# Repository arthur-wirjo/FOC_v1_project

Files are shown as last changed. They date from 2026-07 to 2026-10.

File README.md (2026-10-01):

# DIY FOC Motor Controller V1: Custom Hardware & Firmware from Scratch 

FOC_v1 3_pic
FOC_v1 3_pic2
FOC_v1 3_setup2
FOC_v1 0-1 2

A custom-designed, 60V 50A Field Oriented Control (FOC) BLDC motor controller built from scratch. Designed for high-performance robotics, featuring a 4-layer power PCB, isolated USB telemetry, and CAN bus communication.

## Overview

I started this project to deeply understand the hardware architecture of modern, high-power motor drivers like the VESC and ODrive. Instead of just buying an off-the-shelf driver, I wanted to design one from the ground up to learn the intricacies of power electronics, mixed-signal PCB layout, gate driving, and hardware debugging.

The system is split into a 4-layer main power board (handling the MCU and 60V power stage) and a separate 2-layer magnetic encoder board mounted directly to the motor. This approach kept the overall footprint compact and reduced manufacturing costs.

As the project progressed, it evolved beyond "build a VESC clone" into writing a full custom bare-metal FOC firmware stack from scratch — more on why below. As of 28 September 2026, the board runs true closed-loop Field-Oriented Control, with working current control and smooth closed-loop velocity control of the motor.

## Key Features

* **Working Closed-Loop FOC:** Fully custom bare-metal firmware achieves smooth closed-loop current control and velocity control.
* **60V Power Stage:** 60V-rated MOSFETs capable of handling 10S Li-Po battery voltages and regenerative braking spikes.
* **Precision Current Sensing:** 1mΩ shunt resistors utilizing strict Kelvin connections and RC-filtered differential amplifiers.
* **Isolated Telemetry:** ADuM3160-based USB isolation to protect the host computer from catastrophic 60V transients during live tuning.
* **Robust Communication:** TJA1051T/3 CAN bus transceiver with 120Ω termination for robot networking.
* **Modular Encoder:** Separate 2-layer AS5048A magnetic encoder PCB using JST-GH SMD connectors.

## Hardware

### Computing & Control
* **Microcontroller:** STM32F405RGT6 (Chosen for its floating-point unit, advanced motor control timers, and native VESC compatibility)
* **Gate Driver:** TI DRV8301 (Features a built-in 5V buck converter and dual current shunt amplifiers. Chosen over the DRV8323 for VESC compatibility)

### Power Stage
* **MOSFETs:** Infineon IRFS7530 in D2PAK-7 (Rated for 60V, providing ample headroom for a 10S ~40V battery and regenerative braking)
* **Current Sense:** Yageo PU2512FK-070R001L (1mΩ, 2W metal alloy shunts)
* **Protection:** Littelfuse SMCJ43A TVS Diode (Clamps dangerous voltage spikes generated by motor back-EMF during hard braking)
* **Connectors:** Amass XT90-S (Anti-spark) for battery input

### Sensing & Telemetry
* **Encoder:** AMS AS5048A (14-bit absolute magnetic encoder reading a 6x2.5mm diametrically magnetized NdFeB magnet)
* **Temperature:** Murata 10kΩ 0603 NTC Thermistor (Placed directly adjacent to the MOSFETs to monitor power stage thermals)
* **Voltage Sensing:** 39kΩ / 2.2kΩ voltage divider to safely scale the 60V bus down to the STM32's 3.3V ADC range

## PCB Design & Layout

The board utilizes a 4-layer stackup to safely separate high-current paths from delicate digital signals:
* **Layer 1 (Top):** Components, massive copper polygons for Motor Phases and 42V supply.
* **Layer 2 (Inner 1):** Solid GND plane (Acts as an EMI shield for the signal layer).
* **Layer 3 (Inner 2):** Signal routing (SPI, CAN, Gate Drive traces).
* **Layer 4 (Bottom):** Additional GND and 42V copper pours, heavily via-stitched to the top layer to maximize current carrying capacity and thermal dissipation.

## Challenges and Lessons Learned

Building a high-power motor controller from scratch provided an intense, hands-on education in hardware and firmware debugging.

### Solder Wicking and Clearance Tolerances (V1.0)
After freshly soldering the V1.0 PCB, I felt an unusually strong resistance when I tried to rotate the motor by hand. I learned this is caused by back-EMF when phase wires are shorted together. Multimeter testing confirmed that V++, GND, and all three motor phases were dead-shorted.

Upon inspection, I realized the clearance between my GND copper pour and the soldering pads for V++ and the phase wires was very small (0.15mm). When hand-soldering the massive motor wires, the liquid solder easily wicked across that tiny gap into the GND pour.

For V1.1, I redesigned the board with strict Net Classes, increasing the clearance around high-power wire pads to 0.6mm to create a physical "moat", while keeping the MCU digital clearance at 0.15mm for dense routing.

### The "Bad Internet Symbol" Trap (V1.1)
After successfully assembling V1.1 with new stencils and corrected clearances, the board still exhibited a short between V++, GND, and the phase wires.

I started isolating the issue by desoldering components one by one. I checked a bare V1.0 board and found no shorts, meaning the layout itself wasn't fundamentally shorted. I desoldered the MCU and gate driver — the short was still there. Finally, I desoldered the high-side MOSFETs one by one. Removing the last high-side MOSFET finally severed the short between V++ and the motor phases.

I probed the desoldered MOSFET and found a short between Pin 7 and the Source pins (Pins 2-6). Initially, I thought the MOSFET had overheated and failed closed during hot-plate reflow. However, I looked into the Infineon datasheet and saw a catastrophic error in the third-party CAD symbol I had downloaded.

The symbol incorrectly labeled Pin 7 as "Drain". In reality, the D2PAK-7 package uses the large back EPAD as the Drain, and Pins 2 through 7 are *all* Source pins. Because I followed the flawed schematic, my PCB layout drew a massive copper pour that physically connected the Drain (EPAD) to the Source (Pin 7). The PCB itself was shorting the circuit by design, while the MOSFETs were actually unharmed.

**Lesson learned:** Never trust third-party CAD footprints without verifying against the manufacturer's datasheet.

### The USB D+/D- Swap (V1.2)
With the phase-short issue resolved, V1.2 soldered up cleanly with no shorts between V++, GND, or the phase wires. After hours of VESC firmware macro configuration, I successfully flashed VESC firmware onto the board. However, the board never enumerated over USB — nothing populated on the host PC.

I re-checked the firmware configuration and it looked correct, so I moved to the hardware. It turned out to be a wiring mistake on my end, though the confusing pin naming in the schematic symbol didn't help: instead of connecting DP1↔DP2 and DN1↔DN2 (the isolator-side and MCU-side USB differential pairs), I had wired DP1↔DN1 and DP2↔DN2 — crossing the differential pairs instead of linking them straight through. I corrected this for V1.3.

### The Mysterious Non-Enumerating USB (V1.3)
V1.3 fixed the DP/DN wiring mistake. USB still did not enumerate.

At this point I was confident the hardware was correct, so I wrote a minimal bare-metal STM32 firmware (via STM32CubeMX, STM32CubeIDE, and STM32CubeProgrammer) with nothing but a USB CDC "hello world" to test enumeration independently of VESC firmware. It worked immediately — the host PC detected the board and the virtual COM port came up cleanly. This confirmed the hardware (including the USB isolation and the DP/DN fix) was fine, and the problem was somewhere inside VESC firmware itself.

After a weekend of digging, my working theory is that VESC firmware assumes VBUS sensing on a specific pin by default, which on my board doesn't correspond to an actual VBUS-sensing net — that pin (PA9 / TIM1_CH2) is repurposed as a motor PWM output on my hardware. If VESC firmware is waiting on a VBUS-sense signal that physically doesn't exist on my board, USB enumeration would never complete, since the firmware assumes the connection is dead.

Rather than dig further into VESC's fairly large and unfamiliar codebase to patch around this, I decided to use this as an opportunity to learn embedded systems more deeply from first principles by writing my own bare-metal FOC firmware from scratch.

### The Deceiving Cogging Torque (Open-Loop Commutation)
After first achieving open-loop commutation, I later struggled to reproduce it and assumed something had regressed in the firmware. After investigation, I realized the real cause: during my initial successful test, the motor had warmed up from repeated open-loop parameter tuning, which reduced its cogging torque (magnetic detent force) enough for the open-loop drive to overcome it smoothly. On a cold motor, the same open-loop parameters weren't enough to break through cogging torque cleanly. This was a good reminder that motor behavior is temperature-dependent, and that "it worked once" isn't the same as "it's tuned correctly."

### Missing Bulk Decoupling Capacitor (Current Sensing Noise)
While debugging noisy phase current readings, a senior pointed out that the DRV8301's built-in 5V buck converter was missing a bulk decoupling capacitor on my board. Without it, switching-induced ripple on the 5V rail was likely feeding through to the gate driver's built-in current sense amplifiers, degrading signal quality. I added the missing capacitor directly onto the existing V1.3 board (Frankenstein-style, dead-bug soldered), which noticeably cleaned up the current readings enough for stable closed-loop control. This will be properly integrated into the layout for the next PCB revision.

## Custom Firmware Development

Since abandoning VESC firmware, I've been built a custom bare-metal firmware stack using STM32CubeMX, STM32CubeIDE, and FreeRTOS (for telemetry and state management), with the actual FOC control loop implemented as a hardware-timer/ADC-interrupt-driven routine.

### MCU Pinout

**PWM (TIM1, Center-Aligned, Complementary Outputs)**
| Pin | Function |
|---|---|
| PA8 | TIM1_CH1 |
| PA9 | TIM1_CH2 |
| PA10 | TIM1_CH3 |
| PB13 | TIM1_CH1N |
| PB14 | TIM1_CH2N |
| PB15 | TIM1_CH3N |

**ADC (Current & Voltage Sensing)**
| Pin | Function |
|---|---|
| PA0 | ADC1_IN0 — Phase A Current |
| PA1 | ADC2_IN1 — Phase C Current |
| PA2 | ADC3_IN2 — VBUS Voltage Sensing |
| PA3 | ADC3_IN3 — MOSFET Temperature |

**DRV8301 Gate Driver (SPI1)**
| Pin | Function |
|---|---|
| PC1 | EN_GATE |
| PC2 | DC_CAL |
| PC0 | nFAULT (EXTI0) |
| PB3 | SPI1_SCK |
| PB4 | SPI1_MISO |
| PB5 | SPI1_MOSI |
| PD2 | CS |

**Encoder (SPI3)**
| Pin | Function |
|---|---|
| PC10 | SPI3_SCK |
| PC11 | SPI3_MISO |
| PC12 | SPI3_MOSI |
| PA15 | CS |

**CAN**
| Pin | Function |
|---|---|
| PB8 | CAN1_RX |
| PB9 | CAN1_TX |

**USB**
| Pin | Function |
|---|---|
| PA11 | D- |
| PA12 | D+ |

> **Critical note:** VBUS sensing on PA9 is intentionally *not* used — PA9 is a motor PWM pin on this board (see the V1.3 debugging story above). USB is forced to enumerate without relying on VBUS sensing.

### STM32CubeMX Configuration Notes
* Deadtime configured on the PWM timer to prevent shoot-through.
* Center-aligned PWM mode for reduced current ripple.
* ADC sampling is hardware-synchronized to PWM switching using TIM1's "Update Event" as the ADC "Trigger Event Selection," so current is always sampled at a consistent point in the switching cycle.
* Third phase current is reconstructed using Kirchhoff's Current Law rather than measured directly (only two shunts are sensed).
* ADC current sensing uses **injected conversion mode** so it can be hardware-triggered directly by the timer.
* ADC interrupt enabled in NVIC settings for the current-sensing ADC.
* Encoder SPI configured with DMA in full-duplex master mode.
* USB configured using the USB CDC class for direct serial communication with the host PC.

### Firmware Development Progress
1. ✅ Pinout and hardware configuration in CubeMX
2. ✅ USB CDC enumeration working
3. ✅ DRV8301 register read helper function + gate driver wake-up sequence
4. ✅ SPI encoder DMA callback
5. ✅ Open-loop SPWM commutation and tuning
6. ✅ DRV8301 register write helper function for current amplifier gain configuration
7. ✅ ADC hardware interrupt callback for current sensing (`HAL_ADC_ConvCpltCallback`)
8. ✅ FOC algorithm implemented inside `HAL_ADC_ConvCpltCallback`
9. ✅ Closed-loop current control achieved
10. ✅ Closed-loop velocity control achieved — smooth motor spin under true FOC

### Current Firmware State
* Closed-loop Field-Oriented Control is working on hardware: the motor spins smoothly under closed-loop velocity control, and current can be commanded and regulated directly.
* Open-loop SPWM commutation, ADC-synchronized current sensing, and gate driver configuration are all validated and stable.
* Next steps: Implement automatic misalignment calibration, eccentricity calibration, current and voltage PI tuning, and automatic motor R and L measurement. 

## Current Status
* **V1.0 & V1.1:** Deprecated — used for footprint verification and short-circuit debugging (solder wicking clearance issue, mislabeled MOSFET footprint).
* **V1.2:** Deprecated — resolved the phase-short issues from V1.0/V1.1, but had a USB differential pair wiring mistake (DP/DN crossed) that prevented USB enumeration.
* **V1.3:** Current hardware revision. USB wiring fixed and verified via custom bare-metal USB CDC test firmware. Pivoted away from VESC firmware after diagnosing a VBUS-sensing incompatibility, to a fully custom bare-metal FOC firmware stack. Closed-loop FOC is achieved and validated on hardware. Smooth closed-loop velocity control and current control are both working, following a fix for missing 5V rail decoupling.

## Project Timeline

| Date | Milestone |
|---|---|
| Jun 5 | Project start |
| Jun 19 | Theory research complete |
| Jul 2 | Schematic & component sourcing complete |
| Jul 13 | V1.0 PCB layout complete |
| Jul 23 | V1.0 assembled |
| Jul 27 | V1.0 testing — discovered phase/GND short from insufficient copper clearance (0.15mm) |
| Jul 30 | V1.1 redesigned with wider clearances |
| Aug 22 | V1.1 assembled — short persisted |
| — | Root cause found: mislabeled MOSFET footprint (Drain/Source swap) |
| Aug 28 | V1.2 arrives (footprint fixed) |
| — | Discovered incorrect USB D+/D- wiring |
| Sep 9 | V1.3 arrives (USB wiring corrected) |
| Sep 13 | Began VESC firmware integration — blocked by USB enumeration failure |
| Sep 17 | Diagnosed VBUS-sensing conflict; pivoted to custom bare-metal firmware |
| Sep 19 | Open-loop commutation achieved (later traced intermittent failures to motor-temperature-dependent cogging torque) |
| Sep 22 | ADC current sensing achieved (noisy — later traced to missing decoupling capacitor) |
| Sep 24 | Fixed missing decoupling capacitor; current sensing quality improved |
| Sep 25 | Closed-loop current control achieved |
| **Sep 28** | **Closed-loop velocity control achieved — true FOC working** |

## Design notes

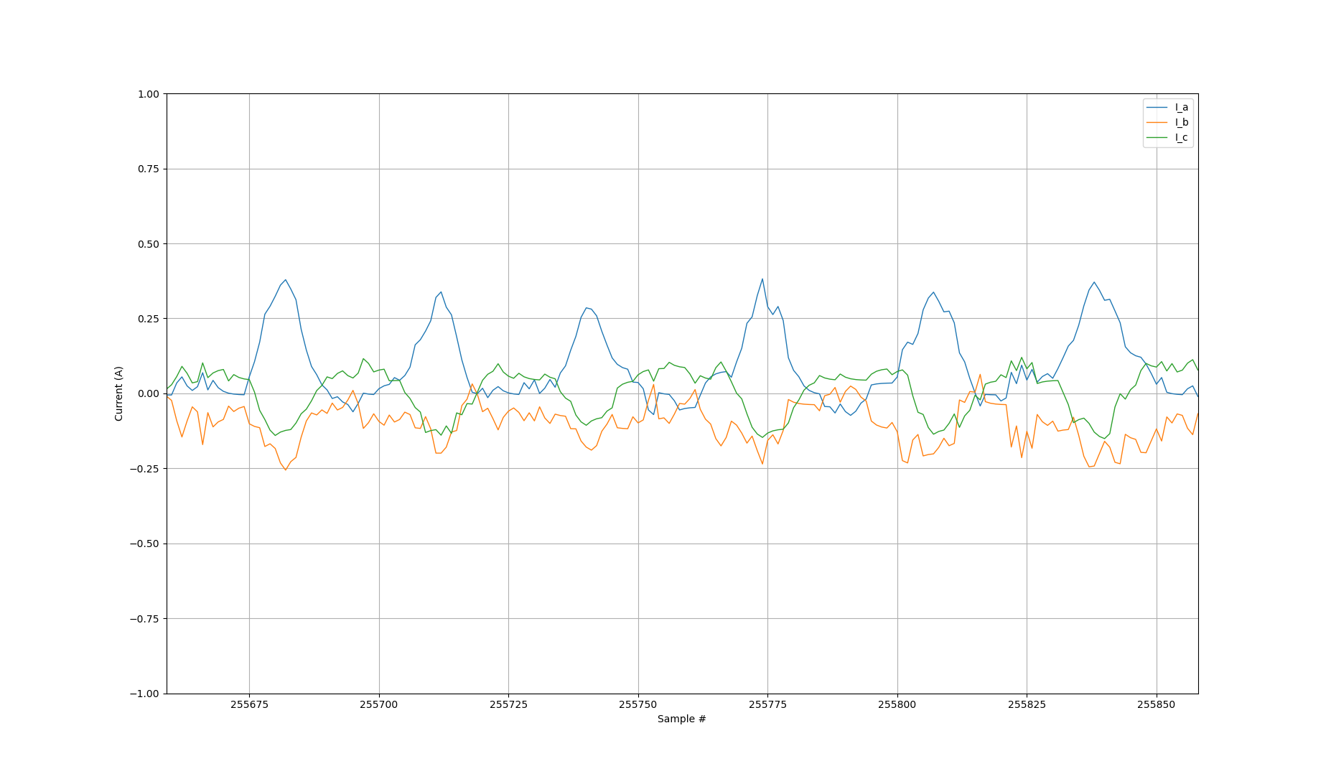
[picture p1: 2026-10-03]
current_graphing/FOC_current_telemetry.png

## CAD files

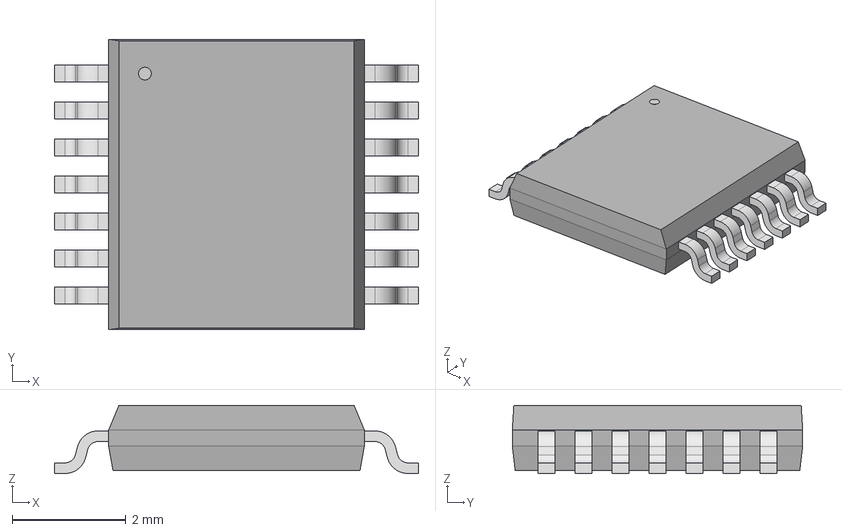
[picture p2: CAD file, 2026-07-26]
Component EDA Models/AS5048A_HTSP/TSSOP14_AMS.step
6.40 x 5.11 x 1.20 mm

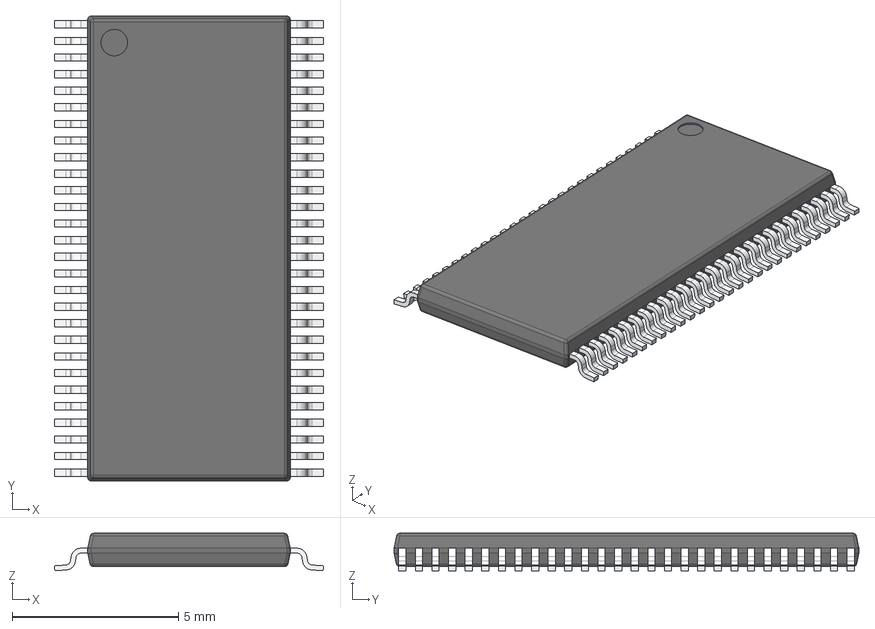
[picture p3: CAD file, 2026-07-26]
Component EDA Models/DRV8301DCAR/DCA0056A.stp
8.10 x 14.0 x 1.13 mm
BODY-TSSOP
LEAD-TSSOP x 56
DAP

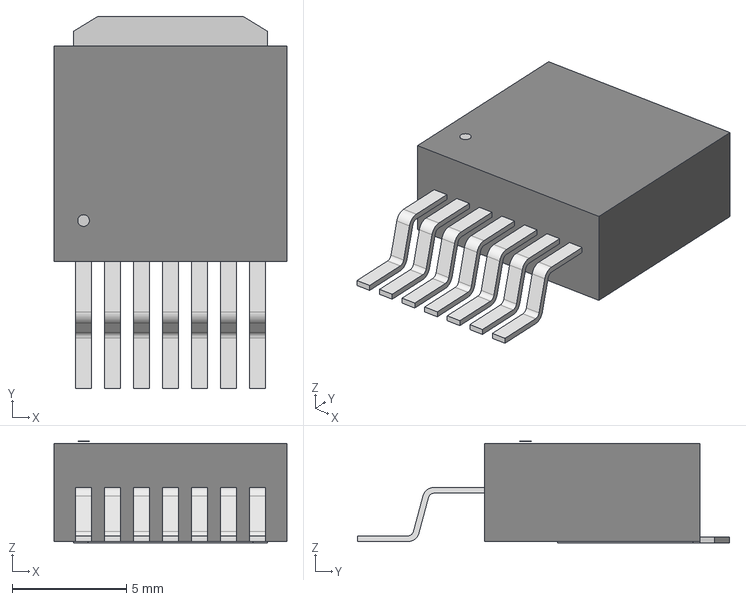
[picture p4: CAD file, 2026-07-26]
Component EDA Models/IRFS7530TRL7PP/PG-TO263-7_INF.step
10.2 x 16.3 x 4.45 mm

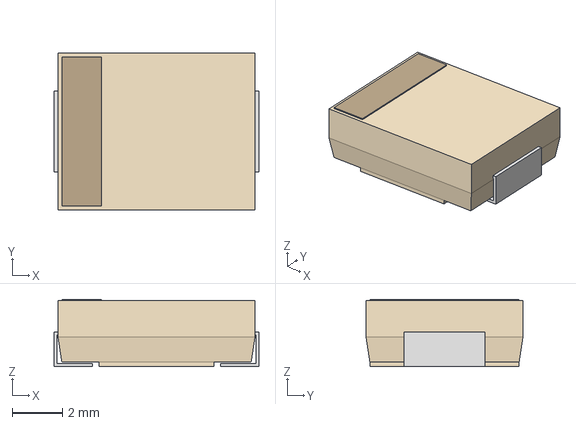
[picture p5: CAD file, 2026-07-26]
Component EDA Models/SMCJ43A/SMCJSeries_LTF.step
8.13 x 6.22 x 2.67 mm

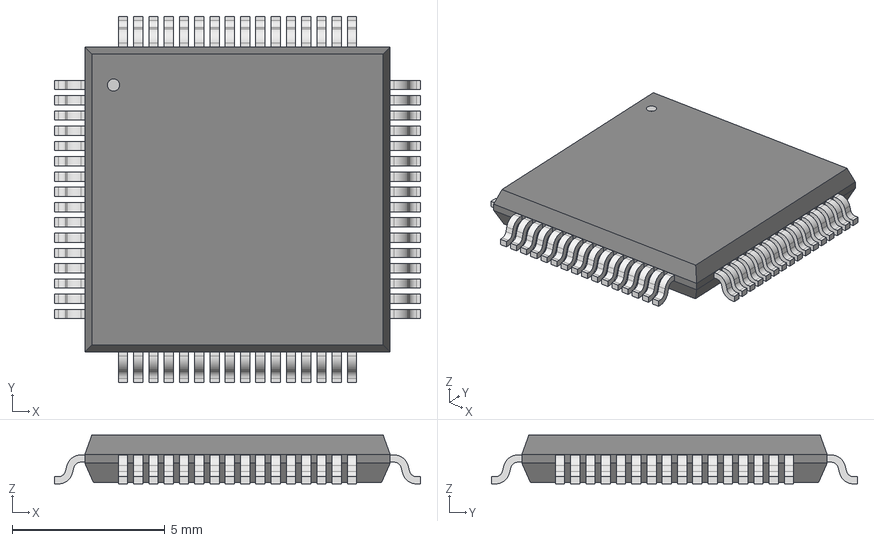
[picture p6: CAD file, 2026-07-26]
Component EDA Models/STM32F405RGT6/LQFP64-10x10mm.step
12.0 x 12.0 x 1.60 mm

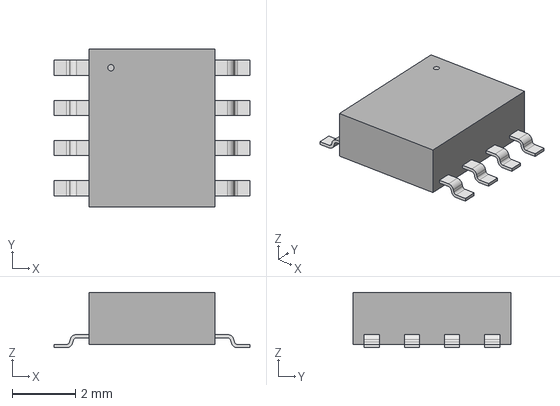
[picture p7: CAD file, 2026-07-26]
Component EDA Models/TJA1051T-3-1J/SO8_SOT96-1_NXP.step
6.20 x 5.00 x 1.75 mm

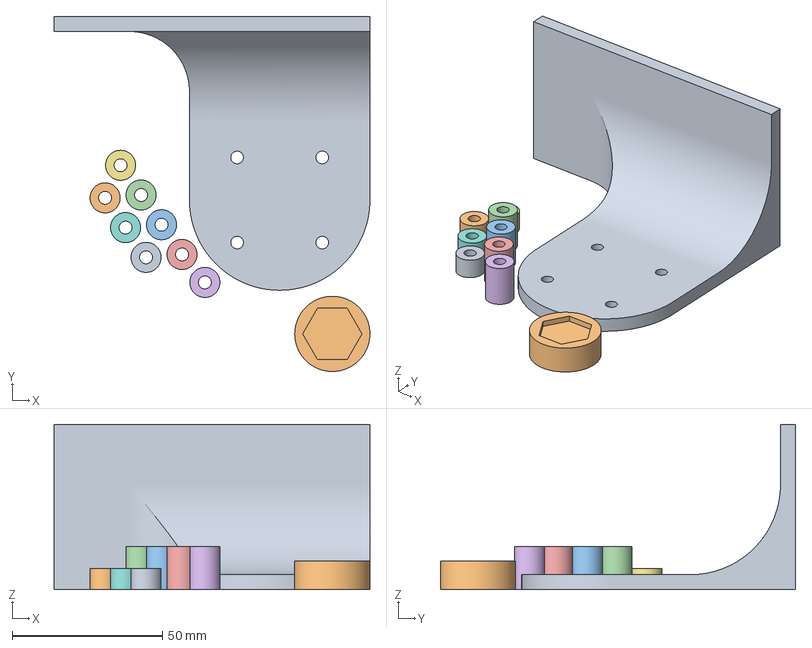
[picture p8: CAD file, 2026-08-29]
Mechanical Testing Rig/3D Print Files/3D print plate file.3mf
105.0 x 118.0 x 55.0 mm
stand.STEP
custom encoder magnet coupler.STEP
encoder spacer.STEP x 4
stand spacer.STEP x 4

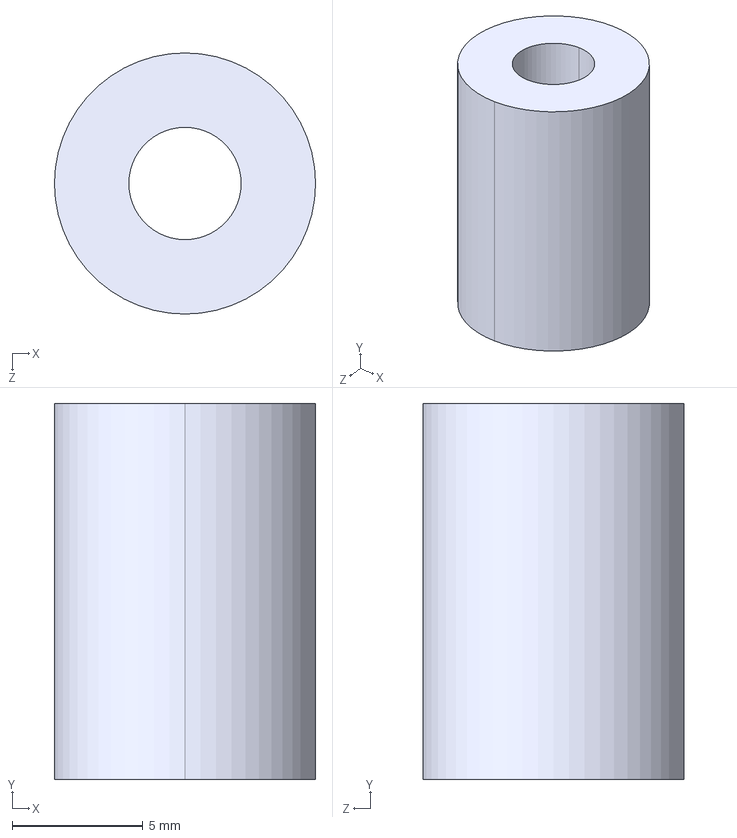
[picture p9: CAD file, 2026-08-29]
Mechanical Testing Rig/3D Print Files/encoder spacer.STEP
10.0 x 14.4 x 10.0 mm

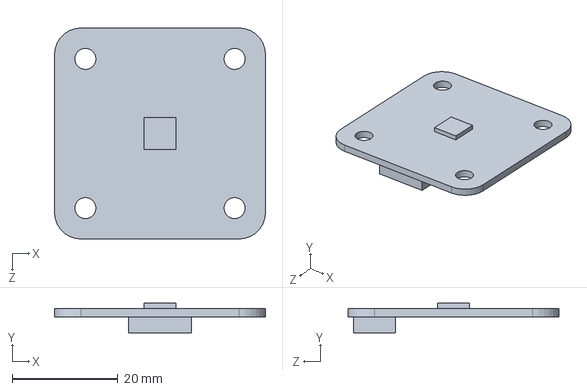
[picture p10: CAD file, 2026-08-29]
Mechanical Testing Rig/encoder pcb.SLDPRT
40.0 x 5.60 x 40.0 mm

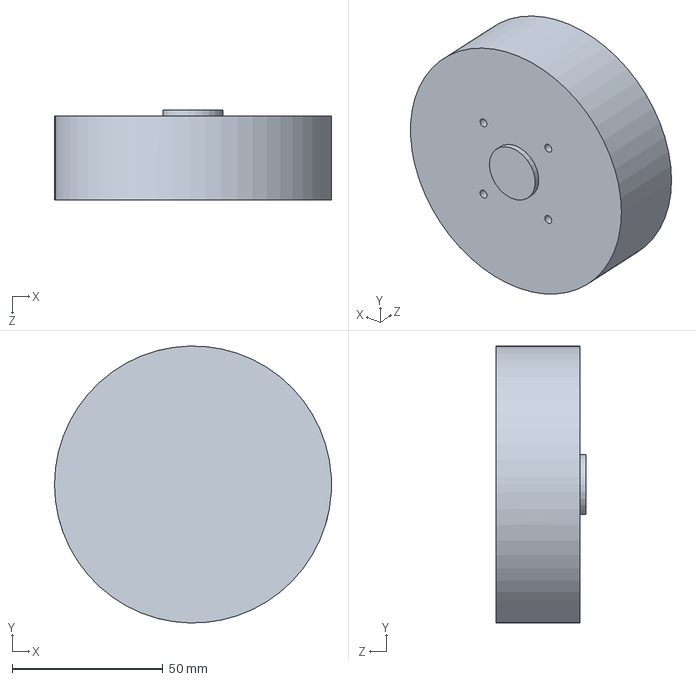
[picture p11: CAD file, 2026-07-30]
Mechanical Testing Rig/Motor.SLDPRT
92.0 x 92.0 x 30.0 mm

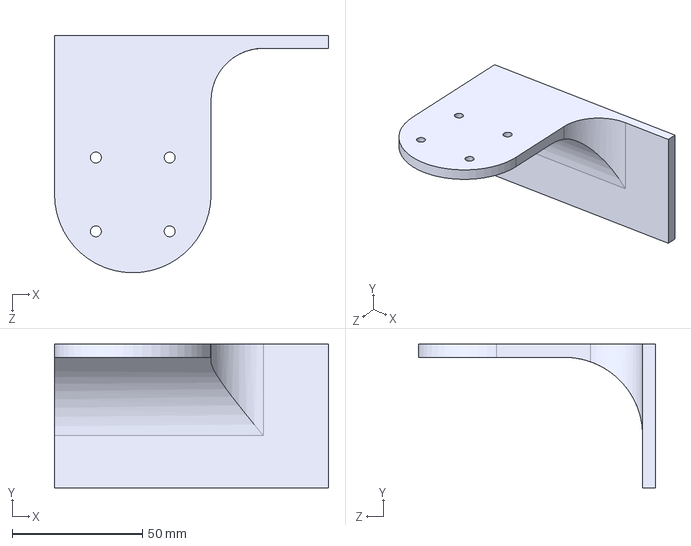
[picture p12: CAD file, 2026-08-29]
Mechanical Testing Rig/3D Print Files/stand.STEP
105.0 x 55.0 x 91.0 mm

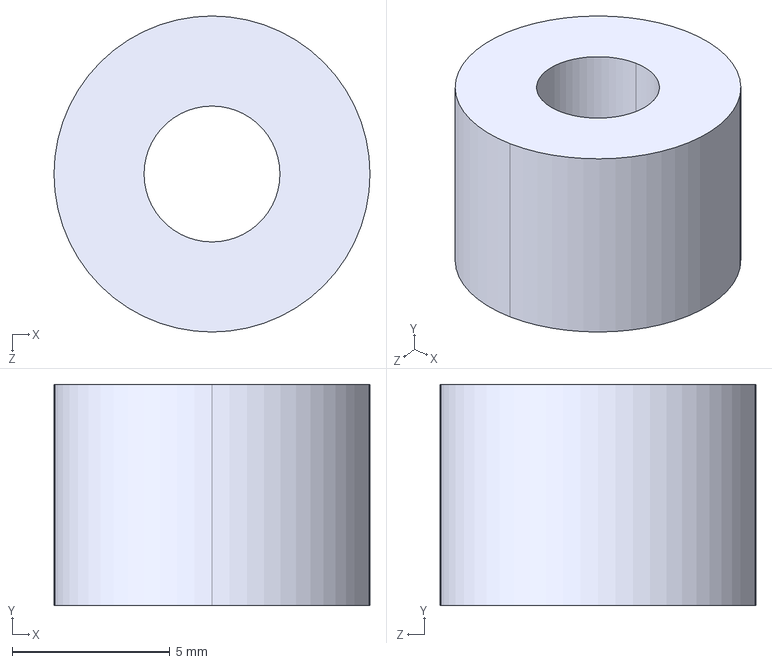
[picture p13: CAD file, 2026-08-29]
Mechanical Testing Rig/3D Print Files/stand spacer.STEP
10.0 x 7.00 x 10.0 mm

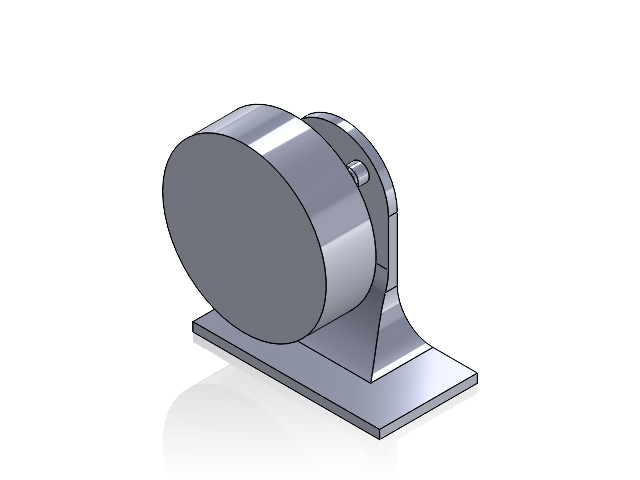
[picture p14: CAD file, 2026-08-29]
Mechanical Testing Rig/0000. Main Assembly.SLDASM
stand spacer x 4
stand
encoder pcb
Motor
custom encoder magnet coupler
encoder spacer x 4

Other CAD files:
Mechanical Testing Rig/custom encoder magnet coupler.SLDPRT
Mechanical Testing Rig/encoder spacer.SLDPRT
Mechanical Testing Rig/stand spacer.SLDPRT
Mechanical Testing Rig/stand.SLDPRT

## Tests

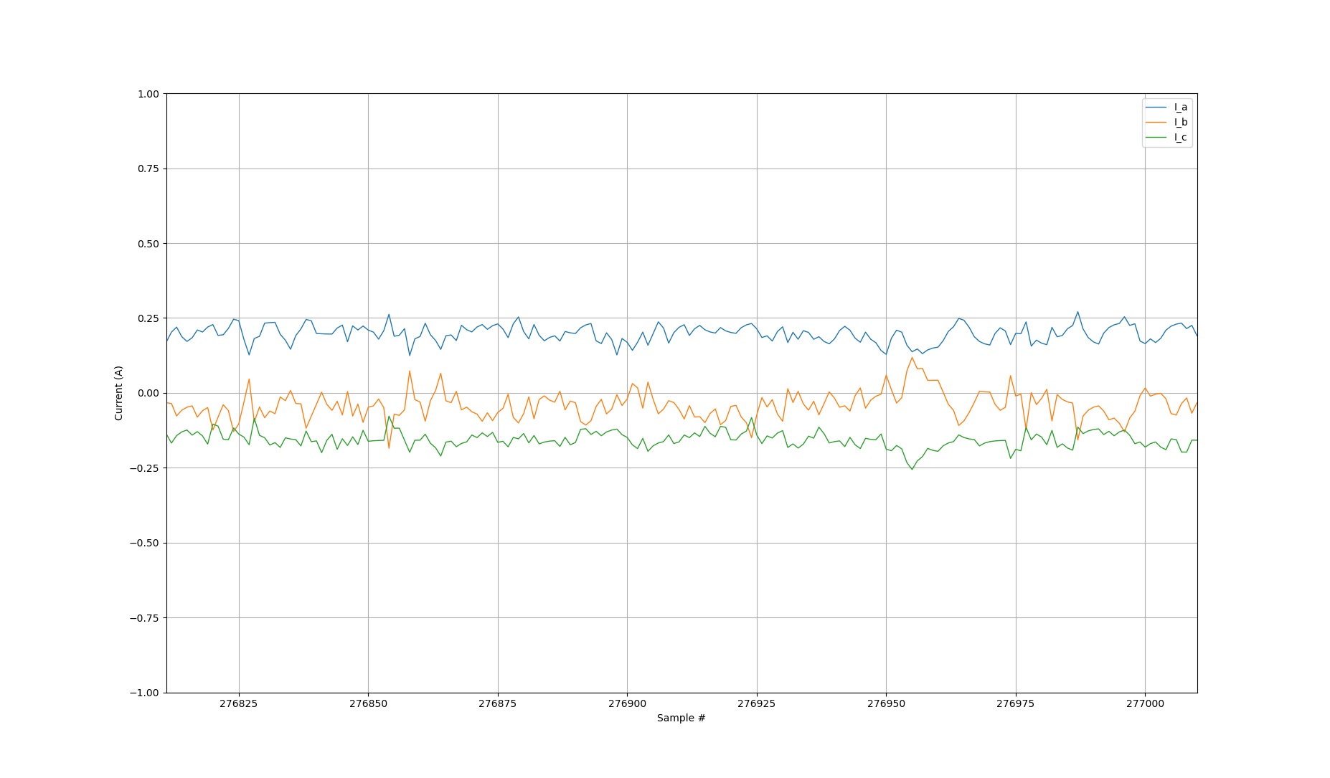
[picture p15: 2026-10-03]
current_graphing/calibration_alignment_telemetry.png

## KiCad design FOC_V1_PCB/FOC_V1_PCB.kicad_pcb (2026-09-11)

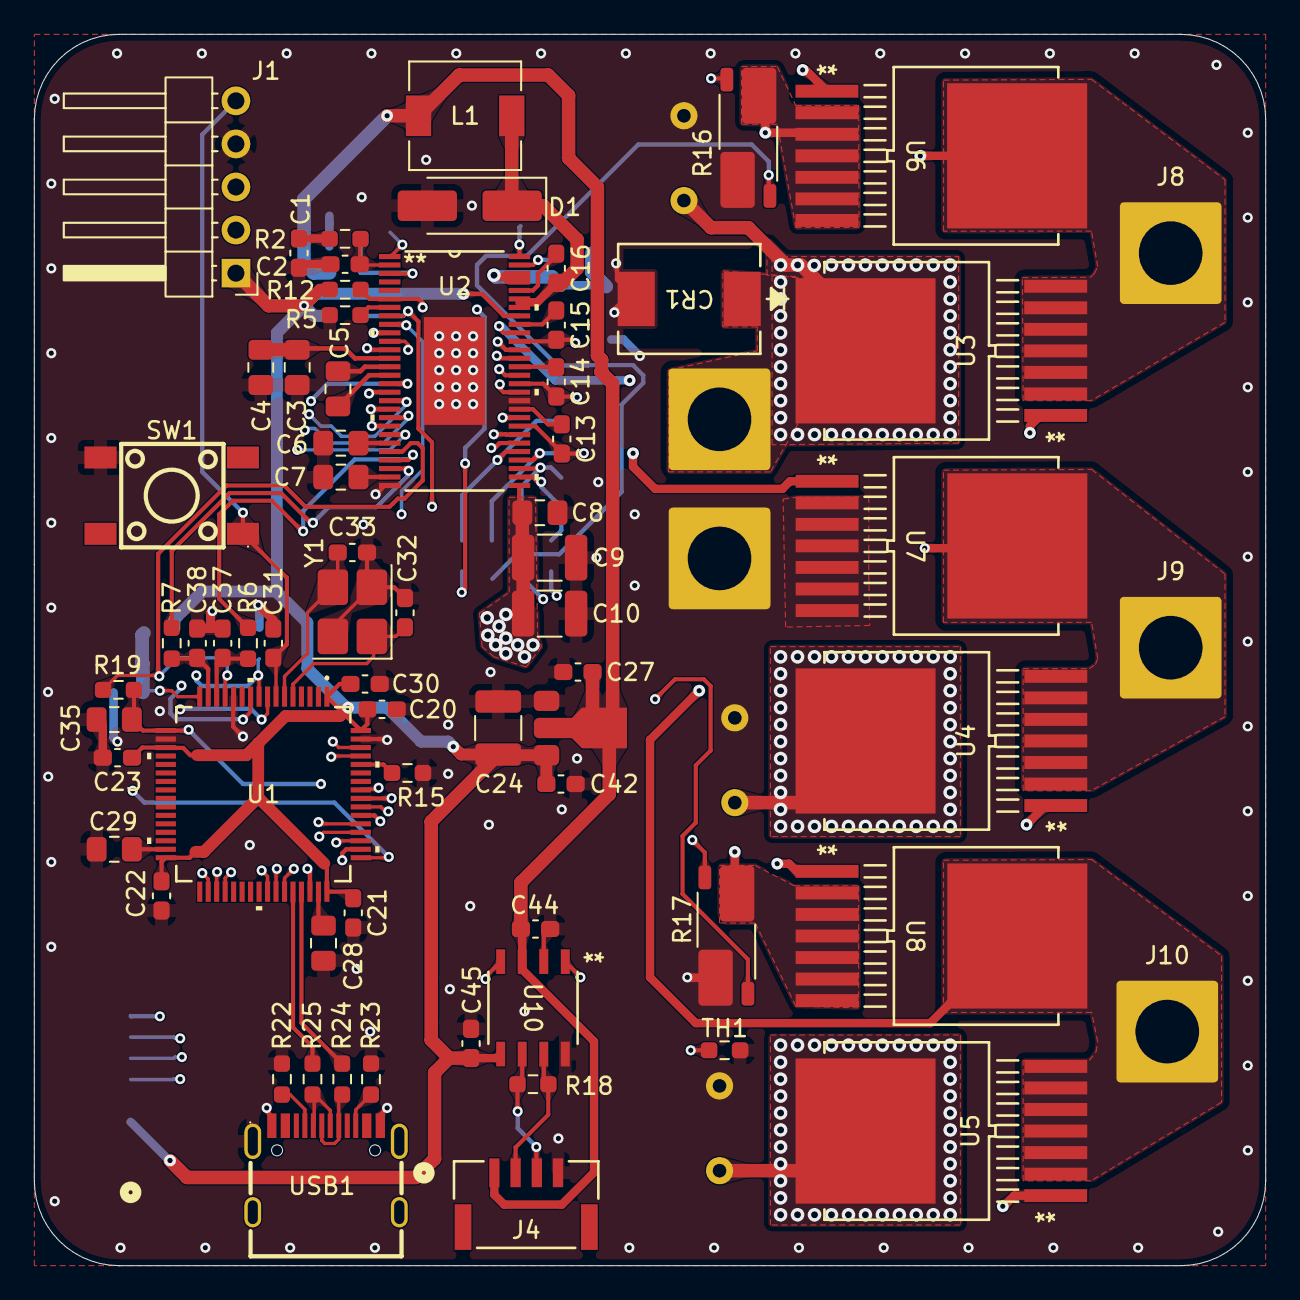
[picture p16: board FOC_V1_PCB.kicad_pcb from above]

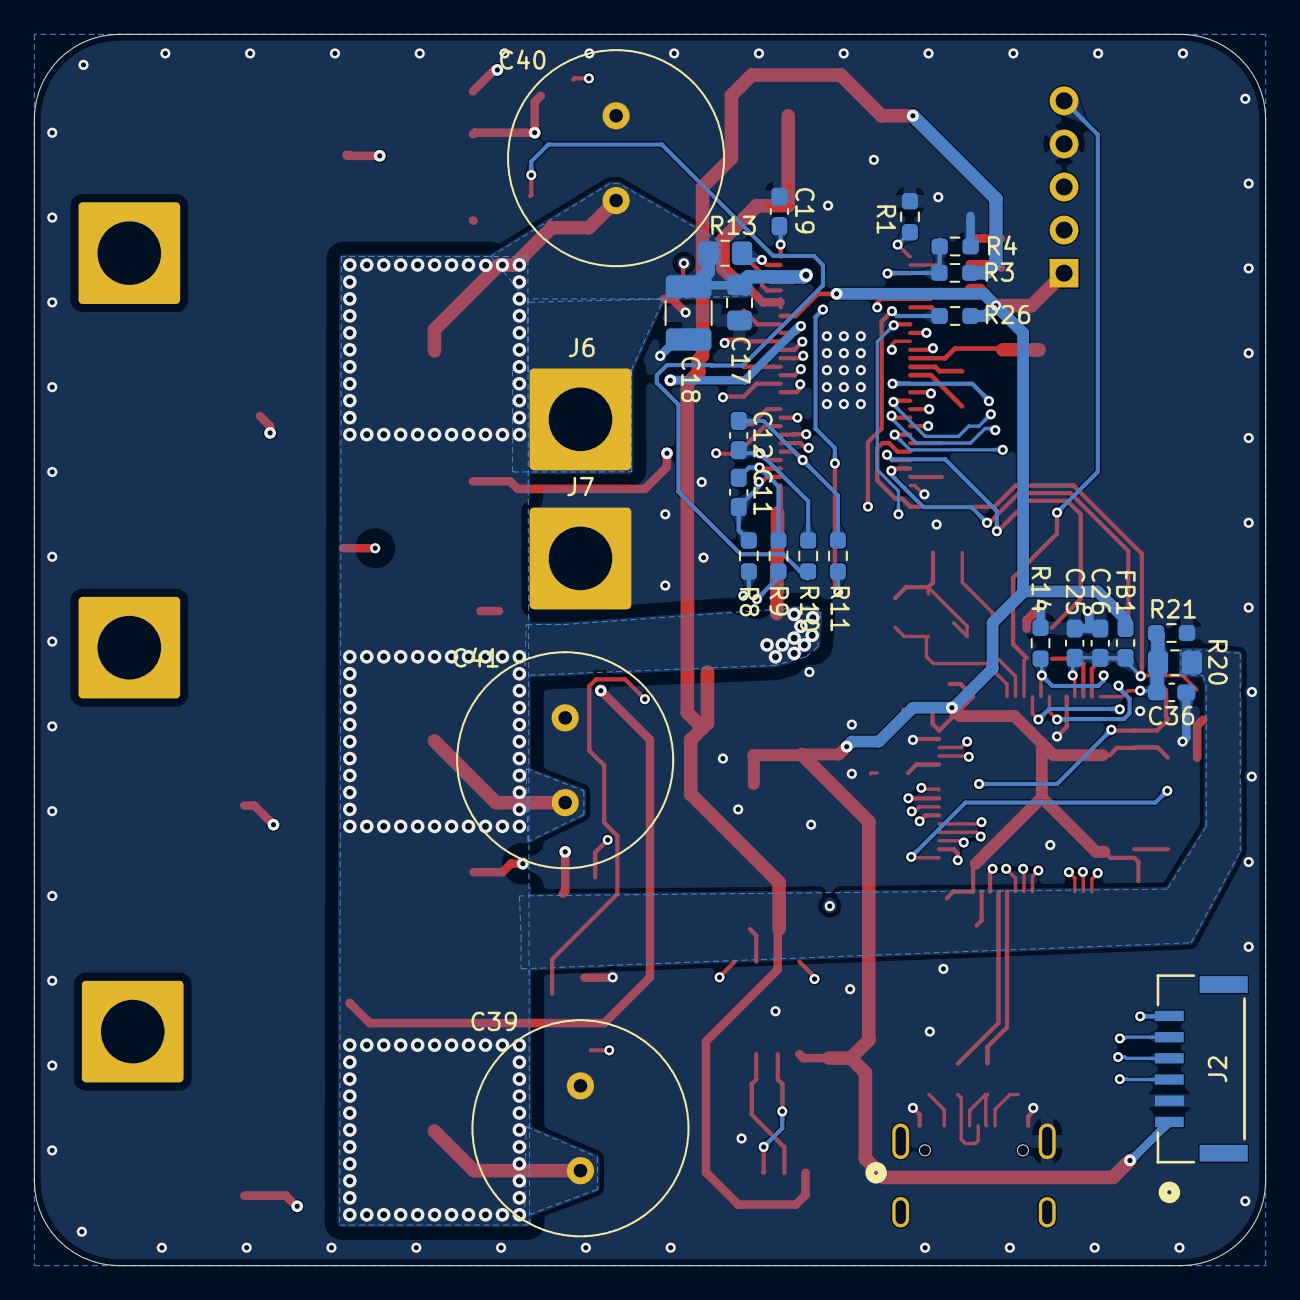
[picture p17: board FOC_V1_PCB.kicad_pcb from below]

Board: 4 copper layers, 72.6 x 72.6 mm, 95 parts (27 on the bottom side), 82 nets.

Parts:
C1: 6.8nF; C_0603_1608Metric_Pad1.08x0.95mm_HandSolder
C2: 120pF; C_0603_1608Metric_Pad1.08x0.95mm_HandSolder
C3, C4: 2.2μF; C_0805_2012Metric_Pad1.18x1.45mm_HandSolder
C5: 22nF; C_0805_2012Metric_Pad1.18x1.45mm_HandSolder
C6, C7, C28, C29, C35: 2.2µF; C_0805_2012Metric_Pad1.18x1.45mm_HandSolder
C8, C17: 100nF; C_0805_2012Metric_Pad1.18x1.45mm_HandSolder
C9, C10, C18: 4.7µF; C_1210_3225Metric_Pad1.33x2.70mm_HandSolder
C11, C12, C37, C38: 2.2nF; C_0603_1608Metric_Pad1.08x0.95mm_HandSolder
C13, C14, C15: 220nF; C_0603_1608Metric_Pad1.08x0.95mm_HandSolder
C16, C20, C21, C22, C23, C30, C31, C36, C44, C45: 100nF; C_0603_1608Metric_Pad1.08x0.95mm_HandSolder
C19: 15nF; C_0603_1608Metric_Pad1.08x0.95mm_HandSolder
C24: 10µF; C_1210_3225Metric_Pad1.33x2.70mm_HandSolder
C25, C27, C42: 1µF; C_0603_1608Metric_Pad1.08x0.95mm_HandSolder
C26: 10nF; C_0603_1608Metric_Pad1.08x0.95mm_HandSolder
C32, C33: 15pF; C_0603_1608Metric_Pad1.08x0.95mm_HandSolder
C39, C40, C41: 470µF; C_Radial_D12.5mm_H20.0mm_P5.00mm
CR1: SMCJ43A; TVS_Diode_SMCJSeries_LTF
D1: D_Schottky; D_SMA_Handsoldering
FB1: FerriteBead; L_0603_1608Metric_Pad1.05x0.95mm_HandSolder
J1: ST-Link_01x05; PinHeader_1x05_P2.54mm_Horizontal
J2: Enc_MCU_01x06; JST-GH_6pin_CONN_SM06B-GHS-TB_JST
J4: CAN_01x04; JST-GH_4pin_CONN_SM04B-GHS-TB_JST
J6: +V; SolderWire-4sqmm_1x01_D3mm_OD6mm
J7: GND; SolderWire-4sqmm_1x01_D3mm_OD6mm
J8: A; SolderWire-4sqmm_1x01_D3mm_OD6mm
J9: B; SolderWire-4sqmm_1x01_D3mm_OD6mm
J10: C; SolderWire-4sqmm_1x01_D3mm_OD6mm
L1: 22µH; L_6.3x6.3_H3
R1: 205kΩ; R_0603_1608Metric_Pad0.98x0.95mm_HandSolder
R2: 16.2kΩ; R_0603_1608Metric_Pad0.98x0.95mm_HandSolder
R3: 52.3kΩ; R_0603_1608Metric_Pad0.98x0.95mm_HandSolder
R4, R5, R12, R14, R15, R19, R26: 10kΩ; R_0603_1608Metric_Pad0.98x0.95mm_HandSolder
R6, R7: 56Ω; R_0603_1608Metric_Pad0.98x0.95mm_HandSolder
R8, R9, R10, R11: 100Ω; R_0603_1608Metric_Pad0.98x0.95mm_HandSolder
R13: 100kΩ; R_0805_2012Metric_Pad1.20x1.40mm_HandSolder
R16, R17: R_Shunt; R_Shunt_Vishay_WSK2512_6332Metric_T2.66mm
R18: 120Ω; R_0603_1608Metric_Pad0.98x0.95mm_HandSolder
R20: 39kΩ; R_0805_2012Metric_Pad1.20x1.40mm_HandSolder
R21: 2.2kΩ; R_0603_1608Metric_Pad0.98x0.95mm_HandSolder
R22, R23: 5.1kΩ; R_0603_1608Metric_Pad0.98x0.95mm_HandSolder
R24, R25: 22Ω; R_0603_1608Metric_Pad0.98x0.95mm_HandSolder
SW1: TS-1002S-05026C; Button_KEY-SMD_4P-L6.0-W6.0-P4.50-LS9.0
TH1: 10kΩ Thermistor_NTC; R_0603_1608Metric_Pad0.98x0.95mm_HandSolder
U1: STM32F405RGT6; STM32F405_LQFP64-10x10mm
U2: DRV8301DCAR; DRV8301_DCA56_6P35X3P61
U3, U4, U5, U6, U7, U8: IRFS7530TRL7PP; IRFS7530_PG-TO263-7_INF
U10: TJA1051T/3/1J; TJA1051_SO8_SOT96-1_NXP
U11: ME6211; ME6211A33PG-N_SOT89-3
USB1: HYCW498-USBC16-735B; USB-C-SMD_HYCW498-USBC16-735B
Y1: Crystal_GND24; Crystal_SMD_3225-4Pin_3.2x2.5mm_HandSoldering

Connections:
BUCK_+5V: C27.2, C44.1, J4.1, L1.2, R3.2, U10.3 (VCC), U11.2 (VIN)
CAN_H: J4.2, R18.1, U10.7 (CANH)
CAN_L: J4.3, R18.2, U10.6 (CANL)
DRV_DC_CAL: U1.10 (PC2), U2.12 (DC_CAL)
DRV_EN_GATE: R14.1, U1.9 (PC1), U2.16 (EN_GATE)
DRV_GH_A: U2.47 (GH_A), U3.1 (G)
DRV_GH_B: U2.42 (GH_B), U4.1 (G)
DRV_GH_C: U2.37 (GH_C), U5.1 (G)
DRV_GL_A: U2.45 (GL_A), U6.1 (G)
DRV_GL_B: U2.40 (GL_B), U7.1 (G)
DRV_GL_C: U2.35 (GL_C), U8.1 (G)
DRV_HA: U1.41 (PA8), U2.17 (INH_A)
DRV_HB: U1.42 (PA9), U2.19 (INH_B)
DRV_HC: U1.43 (PA10), U2.21 (INH_C)
DRV_LA: U1.34 (PB13), U2.18 (INL_A)
DRV_LB: U1.35 (PB14), U2.20 (INL_B)
DRV_LC: U1.36 (PB15), U2.22 (INL_C)
DRV_SH_A: C15.2, J8.1 (Pin_1_1), U2.46 (SH_A), U3.2 (S), U3.3 (S), U3.4 (S), U3.5 (S), U3.6 (S), U3.7 (S), U6.8 (EPAD)
DRV_SH_B: C14.2, J9.1 (Pin_1_1), U2.41 (SH_B), U4.2 (S), U4.3 (S), U4.4 (S), U4.5 (S), U4.6 (S), U4.7 (S), U7.8 (EPAD)
DRV_SH_C: C13.2, J10.1 (Pin_1_1), U2.36 (SH_C), U5.2 (S), U5.3 (S), U5.4 (S), U5.5 (S), U5.6 (S), U5.7 (S), U8.8 (EPAD)
DRV_SL_A: R16.1, U2.44 (SL_A), U6.2 (S), U6.3 (S), U6.4 (S), U6.5 (S), U6.6 (S), U6.7 (S)
DRV_SL_C: R17.1, U2.34 (SL_C), U8.2 (S), U8.3 (S), U8.4 (S), U8.5 (S), U8.6 (S), U8.7 (S)
DRV_SN1: R11.2, R16.2
DRV_SN2: R9.2, R17.2
DRV_SO1: R6.1, U2.25 (SO1)
DRV_SO2: R7.2, U2.26 (SO2)
DRV_SP1: R10.2, R16.3
DRV_SP2: R8.2, R17.3
DRV_SPI_SCLK: U1.55 (PB3), U2.11 (SCLK)
DRV_SPI_SCS: R26.1, U1.54 (PD2), U2.8 (*SCS)
DRV_SPI_SDI: U1.57 (PB5), U2.9 (SDI)
DRV_SPI_SDO: U1.56 (PB4), U2.10 (SDO)
DRV_nFAULT: R12.1, U1.8 (PC0), U2.6 (*FAULT)
ENC_SPI_SCLK: J2.3, U1.51 (PC10)
ENC_SPI_SCS: J2.6, U1.50 (PA15)
ENC_SPI_SDI: J2.5, U1.53 (PC12)
ENC_SPI_SDO: J2.4, U1.52 (PC11)
GND: C1.2, C2.2, C3.2, C4.2, C6.1, C7.1, C8.2, C9.2, C10.2, C17.2, C18.2, C19.2, C20.2, C21.2, C22.2, C23.2, C24.2, C25.1, C26.1, C27.1, C28.1, C29.1, C30.2, C31.2, C32.2, C33.2, C35.2, C36.2, C37.2, C38.1, C39.2, C40.2, C41.2, C42.2, C44.2, C45.2, CR1.2, D1.2 (A), J1.4, J2.2, J4.4, J7.1 (Pin_1_1), R1.1, R4.2, R5.1, R14.2, R15.2, R16.4, R17.4, R21.2, R22.2, R23.2, SW1.4, TH1.2, U1.12 (VSSA), U1.18 (VSS), U1.63 (VSS), U2.28 (AGND), U2.39 (SL_B), U2.57 (EPAD), U7.2 (S), U7.3 (S), U7.4 (S), U7.5 (S), U7.6 (S), U7.7 (S), U10.2 (GND), U10.8 (S), U11.1 (VSS), USB1.1 (SHELL), USB1.A1B12 (GND), USB1.B1A12 (GND), Y1.2 (G), Y1.4 (G)
LDO_+3.3V: C20.1, C21.1, C22.1, C23.1, C24.1, C30.1, C42.1, C45.1, FB1.2, J1.1, J2.1, R12.2, R26.2, U1.1 (VBAT), U1.19 (VDD), U1.32 (VDD), U1.48 (VDD), U1.64 (VDD), U2.49 (VDD_SPI), U10.5 (VIO), U11.3 (VOUT)
MCU_BUS_VSENSE: C36.1, R20.2, R21.1, U1.16 (PA2)
MCU_CAN_RX: U1.61 (PB8), U10.4 (RXD)
MCU_CAN_TX: U1.62 (PB9), U10.1 (TXD)
MCU_NRST: C31.1, J1.5, SW1.1, U1.7 (NRST)
MCU_NTC: C35.1, R19.2, TH1.1, U1.17 (PA3)
MCU_SWCLK: J1.3, U1.49 (PA14)
MCU_SWDIO: J1.2, U1.46 (PA13)
MCU_USB_DM: R25.2, U1.44 (PA11)
MCU_USB_DP: R24.2, U1.45 (PA12)
MCU_VDDA: C25.2, C26.2, FB1.1, R19.1, U1.13 (VDDA), U2.24 (REF)
unnamed: C1.1, R2.2
unnamed: C16.2, D1.1 (K), L1.1, U2.50 (PH), U2.51 (PH)
unnamed: R15.1, U1.60 (BOOT0)
unnamed: C37.1, R6.2, U1.14 (PA0/WKUP)
unnamed: C38.2, R7.1, U1.15 (PA1)
unnamed: C32.1, U1.5 (PH0/OSC_IN), Y1.1
unnamed: C33.1, U1.6 (PH1/OSC_OUT), Y1.3
unnamed: C29.2, U1.31 (VCAP_1)
unnamed: C28.2, U1.47 (VCAP_2)
unnamed: C7.2, U2.27 (AVDD)
unnamed: C15.1, U2.48 (BST_A)
unnamed: C14.1, U2.43 (BST_B)
unnamed: C16.1, U2.52 (BST_BK)
unnamed: C13.1, U2.38 (BST_C)
unnamed: C2.1, R2.1, U2.2 (COMP)
unnamed: C5.1, U2.14 (CP1)
unnamed: C5.2, U2.15 (CP2)
unnamed: R5.2, U2.7 (DTC)
unnamed: C6.2, U2.23 (DVDD)
unnamed: R13.1, U2.55 (EN_BUCK)
unnamed: C3.1, C4.1, U2.13 (GVDD)
unnamed: R1.2, U2.1 (RT_CLK)
unnamed: C12.1, R11.1, U2.33 (SN1)
unnamed: C11.1, R9.1, U2.31 (SN2)
unnamed: C12.2, R10.1, U2.32 (SP1)
unnamed: C11.2, R8.1, U2.30 (SP2)
unnamed: C19.1, U2.56 (SS_TR)
unnamed: R3.1, R4.1, U2.3 (VSENSE)
unnamed: R22.1, USB1.A5 (CC1)
unnamed: R23.1, USB1.B5 (CC2)
unnamed: R25.1, USB1.A7 (DN1), USB1.B7 (DN2)
unnamed: R24.1, USB1.A6 (DP1), USB1.B6 (DP2)
V_Supply_+42V: C8.1, C9.1, C10.1, C17.1, C18.1, C39.1, C40.1, C41.1, CR1.1, J6.1 (Pin_1_1), R13.2, R20.1, U2.29 (PVDD1), U2.53 (PVDD2), U2.54 (PVDD2), U3.8 (EPAD), U4.8 (EPAD), U5.8 (EPAD)

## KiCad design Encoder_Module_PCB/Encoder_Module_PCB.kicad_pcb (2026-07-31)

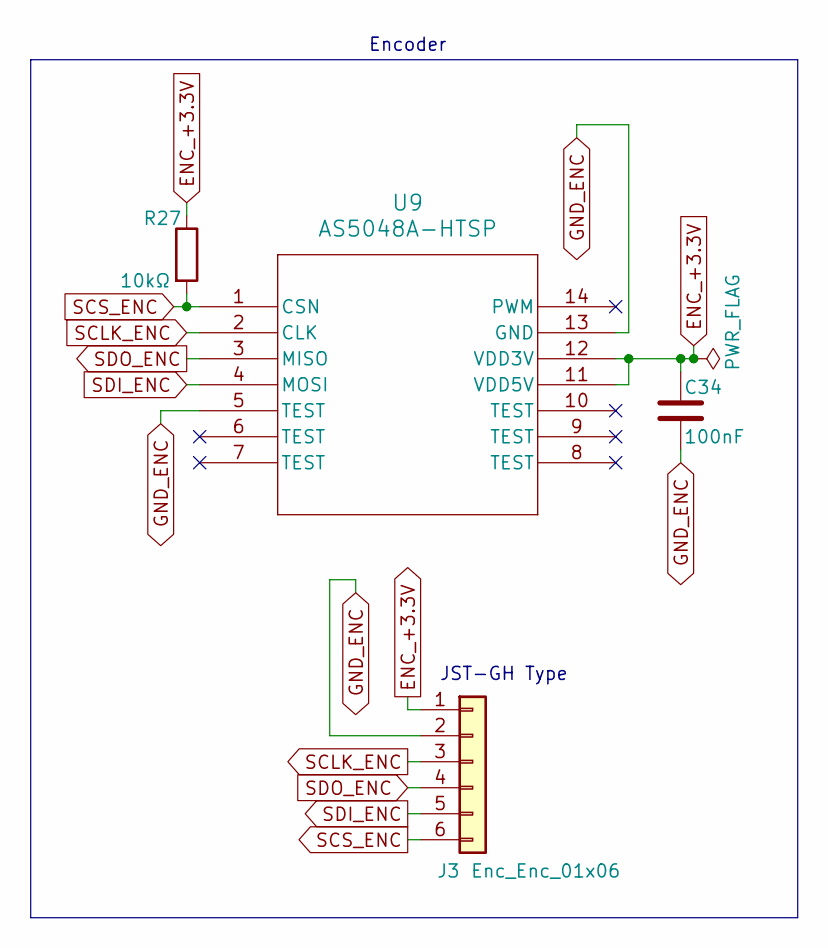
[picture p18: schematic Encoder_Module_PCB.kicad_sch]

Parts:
C34: 100nF; C_0603_1608Metric_Pad1.08x0.95mm_HandSolder
J3: Enc_Enc_01x06; JST-GH_CONN_SM06B-GHS-TB_JST
R27: 10kΩ; R_0603_1608Metric_Pad0.98x0.95mm_HandSolder
U9: AS5048A-HTSP; AS5048A_TSSOP14_AMS

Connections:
ENC_+3.3V: C34.1, J3.1, R27.1, U9.11 (VDD5V), U9.12 (VDD3V)
GND_ENC: C34.2, J3.2, U9.5 (TEST), U9.13 (GND)
SCLK_ENC: J3.3, U9.2 (CLK)
SCS_ENC: J3.6, R27.2, U9.1 (CSN)
SDI_ENC: J3.5, U9.4 (MOSI)
SDO_ENC: J3.4, U9.3 (MISO)

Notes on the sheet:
JST-GH Type
Encoder

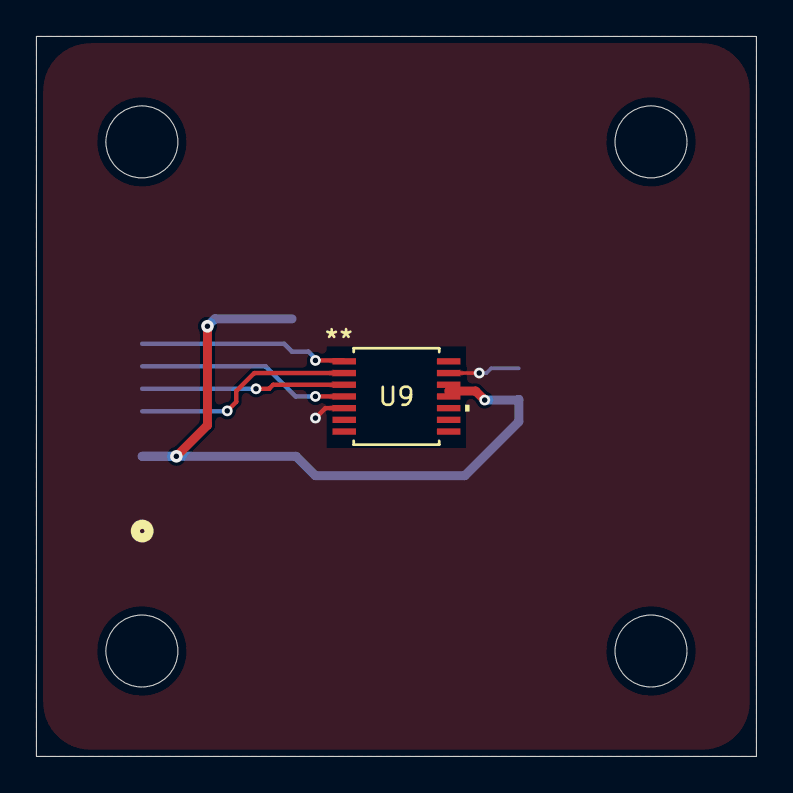
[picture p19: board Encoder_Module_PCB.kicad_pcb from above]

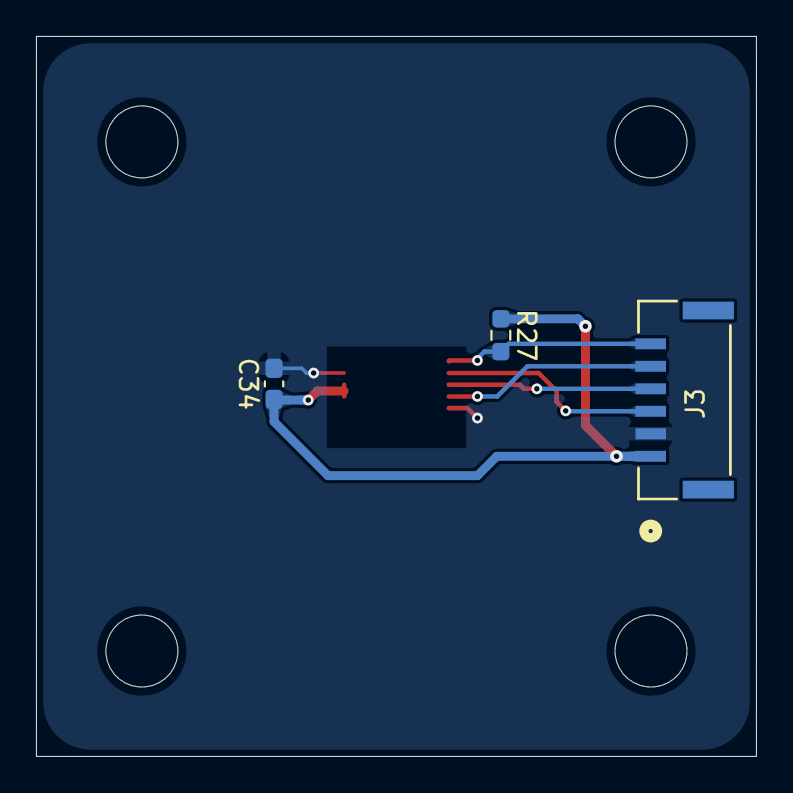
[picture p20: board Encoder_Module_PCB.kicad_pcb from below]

Board: 2 copper layers, 40.0 x 40.0 mm, 4 parts (3 on the bottom side), 6 nets.

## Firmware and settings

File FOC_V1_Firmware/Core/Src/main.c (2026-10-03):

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
/* Includes ------------------------------------------------------------------*/
#include "main.h"
#include "cmsis_os.h"
#include "usb_device.h"

/* USER CODE BEGIN Includes */
#include "usbd_cdc_if.h"
#include <stdio.h>
#include <math.h>
#include <string.h>
/* USER CODE END Includes */

ADC_HandleTypeDef hadc1;
ADC_HandleTypeDef hadc2;
ADC_HandleTypeDef hadc3;

CAN_HandleTypeDef hcan1;

SPI_HandleTypeDef hspi1;
SPI_HandleTypeDef hspi3;
DMA_HandleTypeDef hdma_spi3_rx;
DMA_HandleTypeDef hdma_spi3_tx;

TIM_HandleTypeDef htim1;

/* Definitions for StateTask */
osThreadId_t StateTaskHandle;
const osThreadAttr_t StateTask_attributes = {
  .name = "StateTask",
  .stack_size = 128 * 4,
  .priority = (osPriority_t) osPriorityHigh,
};
/* Definitions for TelemetryTask */
osThreadId_t TelemetryTaskHandle;
const osThreadAttr_t TelemetryTask_attributes = {
  .name = "TelemetryTask",
  .stack_size = 512 * 4,
  .priority = (osPriority_t) osPriorityNormal,
};

/* USER CODE BEGIN PV */
uint16_t as5048a_tx_buffer = 0xFFFF;
uint16_t as5048a_rx_buffer = 0x0000;
volatile MotorState_t motor_state = STATE_OFF;
// ADC
volatile uint16_t raw_adc_a, raw_adc_c;
volatile float offset_a = 2048.0f;
volatile float offset_c = 2048.0f;
// Global FOC variables for telemetry
volatile float global_theta_elec = 0.0f;
volatile float i_a, i_b, i_c;
volatile float i_d, i_q;
volatile float v_d, v_q;
// Current PI Controller states
volatile float integral_d = 0.0f;
volatile float integral_q = 0.0f;
volatile float target_id = 0.0f;
volatile float target_iq = 0.0f;
// Velocity PI Controller states
volatile float current_vel_rads = 0.0f;
volatile float target_vel_rads = 20.0f; // target 10 rad/s (~95rpm) for testing
volatile float prev_theta_mech = 0.0f;
volatile float vel_integral = 0.0f;
volatile float ramped_target_vel = 0.0f;
// Timing constant (168MHz clock and 4199 timer period -> 168Mhz/(2*4200) = 20kHz PWM)
const float DT = 0.00005f;
// Motor constants
const float POLE_PAIRS = 20.0f; // Eaglepower 90kv motor
const float PI_CONST = 3.14159265359f;
volatile float mech_offset = 0.0f;
// High-rate binary telemetry
#define CUR_STREAM_DECIMATION 4 // 20kHz
#define CUR_STREAM_BUF_LEN 256
typedef struct {
  uint16_t seq;
  float i_a;
  float i_b;
  float i_c;
} CurSample_t;
volatile CurSample_t cur_stream_buf[CUR_STREAM_BUF_LEN];
volatile uint16_t cur_stream_head = 0;
volatile uint16_t cur_stream_tail = 0;
volatile uint16_t cur_stream_seq = 0;
osThreadId_t CurStreamTaskHandle;
const osThreadAttr_t CurStreamTask_attributes = {
  .name = "CurStreamTask",
  .stack_size = 512 * 4,
  .priority = (osPriority_t) osPriorityAboveNormal,
};
/* USER CODE END PV */

void SystemClock_Config(void);
static void MX_GPIO_Init(void);
static void MX_DMA_Init(void);
static void MX_ADC1_Init(void);
static void MX_ADC2_Init(void);
static void MX_ADC3_Init(void);
static void MX_TIM1_Init(void);
static void MX_SPI1_Init(void);
static void MX_SPI3_Init(void);
static void MX_CAN1_Init(void);
void StartStateTask(void *argument);
void StartTelemetryTask(void *argument);

/* USER CODE BEGIN PFP */
void StartCurStreamTask(void *argument);
/* USER CODE END PFP */

/* USER CODE BEGIN 0 */

// Wrap angle helper function
static inline float wrap_angle(float angle) {
	while (angle > PI_CONST) {
		angle -= (2.0f * PI_CONST);
	}
	while (angle < -PI_CONST) {
		angle += (2.0f * PI_CONST);
	}
	return angle;
}

// fast sin & cos function
static inline float fast_sin(float x) {
	x = wrap_angle(x);
	float sin_x;
	if (x < 0.0f) {
		sin_x = 1.27323954f * x + 0.405284735f * x * x;
		if (sin_x < 0.0f) {
			sin_x = 0.225f * (sin_x * -sin_x - sin_x) + sin_x;
		} else {
			sin_x = 0.225f * (sin_x * sin_x - sin_x) + sin_x;
		}
	} else {
		sin_x = 1.27323954f * x - 0.405284735f * x * x;
		if (sin_x < 0.0f) {
			sin_x = 0.225f * (sin_x * -sin_x - sin_x) + sin_x;
		} else {
			sin_x = 0.225f * (sin_x * sin_x - sin_x) + sin_x;
		}
	}
	return sin_x;
}
static inline float fast_cos(float x) {
	return fast_sin(x + 1.570796327f); // sin(x + pi/2)
}

// Fast Inverse Square Root for clamping v_d & v_q (calculates 1/sqrt(x))
static inline float fast_inv_sqrt(float number) {
  union {
    float f;
    uint32_t i;
  } conv;

  float x2;
  const float threehalfs = 1.5F;

  x2 = number * 0.5F;
  conv.f = number;
  conv.i = 0x5f3759df - (conv.i >> 1);
  conv.f = conv.f * (threehalfs - (x2 * conv.f * conv.f));
  return conv.f;
}
/* USER CODE END 0 */

/**
  * @brief  The application entry point.
  * @retval int
  */
int main(void)
{
  /* MCU Configuration--------------------------------------------------------*/
  HAL_Init();
  SystemClock_Config();

  /* Initialize all configured peripherals */
  MX_GPIO_Init();
  MX_DMA_Init();
  MX_ADC1_Init();
  MX_ADC2_Init();
  MX_ADC3_Init();
  MX_TIM1_Init();
  MX_SPI1_Init();
  MX_SPI3_Init();
  MX_CAN1_Init();

  /* Init scheduler */
  osKernelInitialize();

  /* Create the thread(s) */
  StateTaskHandle = osThreadNew(StartStateTask, NULL, &StateTask_attributes);
  TelemetryTaskHandle = osThreadNew(StartTelemetryTask, NULL, &TelemetryTask_attributes);
  CurStreamTaskHandle = osThreadNew(StartCurStreamTask, NULL, &CurStreamTask_attributes);

  /* Start scheduler */
  osKernelStart();

  /* Infinite loop */
  while (1)
  {
  }
}

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
/* USER CODE BEGIN 4 */
// Helper function for reading DRV8301 register
uint16_t DRV8301_ReadReg(uint8_t addr) {
	uint16_t tx_data;
	uint16_t rx_data = 0;

	tx_data = (1 << 15) | ((addr & 0x0F) << 11);

	HAL_GPIO_WritePin(GPIOD, GPIO_PIN_2, GPIO_PIN_RESET);
	HAL_SPI_TransmitReceive(&hspi1, (uint8_t*)&tx_data, (uint8_t*)&rx_data, 1, 100);
	HAL_GPIO_WritePin(GPIOD, GPIO_PIN_2, GPIO_PIN_SET);

	for(volatile int i=0; i<50; i++);

	tx_data = 0x0000;
	HAL_GPIO_WritePin(GPIOD, GPIO_PIN_2, GPIO_PIN_RESET);
	HAL_SPI_TransmitReceive(&hspi1, (uint8_t*)&tx_data, (uint8_t*)&rx_data, 1, 100);
	HAL_GPIO_WritePin(GPIOD, GPIO_PIN_2, GPIO_PIN_SET);

	return (rx_data & 0x07FF);
}

// Helper function for writing DRV8301 register
void DRV8301_WriteReg(uint8_t addr, uint16_t data) {
	uint16_t tx_data;
	uint16_t rx_data;

	tx_data = (0 << 15) | ((addr & 0xF) << 11) | (data & 0x07FF);

	HAL_GPIO_WritePin(GPIOD, GPIO_PIN_2, GPIO_PIN_RESET);
	HAL_SPI_TransmitReceive(&hspi1, (uint8_t*)&tx_data, (uint8_t*)&rx_data, 1, 100);
	HAL_GPIO_WritePin(GPIOD, GPIO_PIN_2, GPIO_PIN_SET);

	for(volatile int i = 0; i < 50; i++);
}

// SPI DMA Completion Callback
void HAL_SPI_TxRxCpltCallback(SPI_HandleTypeDef *hspi) {
	if (hspi->Instance == SPI3) {
		HAL_GPIO_WritePin(GPIOA, GPIO_PIN_15, GPIO_PIN_SET);
	}
}

// Hardware ADC Interrupt Callback
void HAL_ADCEx_InjectedConvCpltCallback(ADC_HandleTypeDef *hadc) {
	if (hadc->Instance == ADC1) {
		// Read the raw injected ADC values (0 to 4095)
		raw_adc_a = HAL_ADCEx_InjectedGetValue(&hadc1, ADC_INJECTED_RANK_1);
		raw_adc_c = HAL_ADCEx_InjectedGetValue(&hadc2, ADC_INJECTED_RANK_1);

    // convert raw ticks to amps
		// assume 2048 ticks is exactly 0 Amps, gain = 20, and R_shunt = 0.001
	  // multiplier = 3.3V / (4095 * gain * R_shunt) = 3.3 / (4095 * 20 * 0.001) = 0.040293f
		i_a = ((float)raw_adc_a - offset_a) * 0.040293f;
		i_c = ((float)raw_adc_c - offset_c) * 0.040293f;
		// kirchoff's law: i_a + i_b + i_c = 0
		i_b = -(i_a + i_c);

    // High-rate current telemetry streaming (decimated, non-blocking)
    static uint32_t stream_decim_counter = 0;
    if (motor_state != STATE_OFF) {
      stream_decim_counter++;
      if (stream_decim_counter >= CUR_STREAM_DECIMATION) {
        stream_decim_counter = 0;
        uint16_t next_head = (uint16_t)((cur_stream_head + 1) % CUR_STREAM_BUF_LEN);
        if (next_head != cur_stream_tail) {
          // buffer not full
          cur_stream_buf[cur_stream_head].seq = cur_stream_seq++;
          cur_stream_buf[cur_stream_head].i_a = i_a;
          cur_stream_buf[cur_stream_head].i_b = i_b;
          cur_stream_buf[cur_stream_head].i_c = i_c;
          cur_stream_head = next_head;
        }
      }
    }

		// Get mechanical angle from last SPI DMA transfer
		uint16_t raw_angle = (as5048a_rx_buffer & 0x3FFF);
		float theta_mech = ((float)raw_angle / 16384.0f) * (2.0f * PI_CONST);

    // Velocity calculation with low pass filter
    float delta_theta = wrap_angle(theta_mech - prev_theta_mech);
    prev_theta_mech = theta_mech;
    float raw_vel = delta_theta/DT;
    float alpha = 0.1f; 
    current_vel_rads = (alpha * raw_vel) + ((1.0f - alpha) * current_vel_rads);
		
    float theta_elec = 0.0f;
    float c = 1.0f;
		float s = 0.0f;

    static uint32_t calib_counter = 0;
    static uint8_t kickstart_active = 0;
    static uint32_t kickstart_counter = 0;
    const float KICK_CURRENT = 0.5f;
    const uint32_t KICK_MAX_TICKS = 2000;
    const float BREAKAWAY_VEL_THRESH = 1.0f;

		if (motor_state == STATE_OFF) {
			// motor off: reset integral and set 50% duty cycle
			integral_d = 0.0f;
			integral_q = 0.0f;
      vel_integral = 0.0f;
      ramped_target_vel = 0.0f;
      calib_counter = 0;
      kickstart_active = 0;
      kickstart_counter = 0;
			TIM1->CCR1 = 2099;
			TIM1->CCR2 = 2099;
      TIM1->CCR3 = 2099;

			// trigger next SPI DMA for encoder so its ready when we start
			HAL_GPIO_WritePin(GPIOA, GPIO_PIN_15, GPIO_PIN_RESET);
			HAL_SPI_TransmitReceive_DMA(&hspi3, (uint8_t*)&as5048a_tx_buffer, (uint8_t*)&as5048a_rx_buffer, 1);
			return;
		}
    else if (motor_state == STATE_CALIBRATING) {
      calib_counter++;

      // Force electrical angle to 0
      theta_elec = 0.0f;
      c = 1.0f;
      s = 0.0f;

      if (calib_counter < 16000) {
        // pull into rough alignment
        target_id = 0.35f;
        target_iq = 0.0f;
      } else {
        // actively brake any leftover ringing
        target_id = 0.35f;
        float damp_iq = -0.3f * current_vel_rads;
        if (damp_iq > 0.3f) damp_iq = 0.3f;
        if (damp_iq < -0.3f) damp_iq = -0.3f;
        target_iq = damp_iq; 
      }

      if (calib_counter >= 20000) {
      mech_offset = theta_mech;
      target_id = 0.0f;
      integral_d = 0.0f;
      integral_q = 0.0f;
      vel_integral = 0.0f;
      calib_counter = 0;
      
      kickstart_active = 1;
      kickstart_counter = 0;

      motor_state = STATE_RUNNING;
    }
    }
    else if (motor_state == STATE_RUNNING) {
      theta_elec = wrap_angle((theta_mech - mech_offset) * POLE_PAIRS);
      c = fast_cos(theta_elec);
      s = fast_sin(theta_elec);

      // Velocity PI Controller (TO BE TUNED)
      float Kp_vel = 0.02f;
      float Ki_vel = 0.2f;
      float max_iq = 3.0f;
      
      // 50rad/s^2 max acceleration
      float max_accel_step = 50.0f * DT;

      if (ramped_target_vel < target_vel_rads) {
        ramped_target_vel += max_accel_step;
        if (ramped_target_vel > target_vel_rads) {
          ramped_target_vel = target_vel_rads;
        }
      } else if (ramped_target_vel > target_vel_rads) {
        ramped_target_vel -= max_accel_step;
        if (ramped_target_vel < target_vel_rads) {
          ramped_target_vel = target_vel_rads;
        }
      }

      if (kickstart_active) {
        kickstart_counter++;
        float kick_iq = (target_vel_rads >= 0.0f) ? KICK_CURRENT : -KICK_CURRENT;
        target_iq = kick_iq;

        if (fabsf(current_vel_rads) > BREAKAWAY_VEL_THRESH || kickstart_counter >= KICK_MAX_TICKS) {
          kickstart_active = 0;
          vel_integral = kick_iq;
        }
      } else {
        float err_vel = ramped_target_vel - current_vel_rads;
        vel_integral += err_vel * Ki_vel * DT;
        
        // Velocity Anti-windup
        if (vel_integral > max_iq) vel_integral = max_iq;
        if (vel_integral < -max_iq) vel_integral = -max_iq;

        // Velocity PI control
        target_iq = (Kp_vel * err_vel) + vel_integral;

        // Clamp target_iq for safety
        if (target_iq > max_iq) target_iq = max_iq;
        if (target_iq < -max_iq) target_iq = -max_iq;
      }

      target_id = 0.0f;
    }

    global_theta_elec = theta_elec;

		// Clarke Transform
		float i_alpha = i_a;
		float i_beta = (0.577350269f * i_a) + (1.154700538f * i_b);

		// Park Transform
		i_d = (i_alpha * c) + (i_beta * s);
		i_q = -(i_alpha * s) + (i_beta * c);

		// Current PI Controllers (TO BE TUNED)
		float Kp_cur = 0.02f;
		float Ki_curr = 50.0f;
		float v_max = 0.4f; // max duty cycle variance

		float err_d = target_id - i_d;
		float err_q = target_iq - i_q;

		integral_d += err_d * Ki_curr * DT;
		integral_q += err_q * Ki_curr * DT;

		// Current Anti-windup
		if (integral_d > v_max) integral_d = v_max;
		if (integral_d < -v_max) integral_d = -v_max;
		if (integral_q > v_max) integral_q = v_max;
		if (integral_q < -v_max) integral_q = -v_max;

		// Current PI control
		v_d = (Kp_cur * err_d) + integral_d;
		v_q = (Kp_cur * err_q) + integral_q;

    // Circular voltage limiting (clamping v_d & v_q)
    float v_mag_sq = (v_d * v_d) + (v_q * v_q);
    float v_max_sq = v_max * v_max;

    if (v_mag_sq > v_max_sq) {
      // calculate scalinng factor (v_max / sqrt(v_d^2 + v_q^2))
      float scale = v_max * fast_inv_sqrt(v_mag_sq);
      v_d *= scale;
      v_q *= scale;
    }

		// Inverse Park Transform
		float v_alpha = (v_d * c) - (v_q * s);
		float v_beta = (v_d * s) + (v_q * c);

		// Inverse Clarke Transform & SVPWM (Saddle Injection)
		float v_a = v_alpha;
		float v_b = -0.5f * v_alpha + 0.866025403f * v_beta;
		float v_c = -0.5f * v_alpha - 0.866025403f * v_beta;

		// find min and max for saddle injection
		float v_min_val = v_a;
		if (v_b < v_min_val) v_min_val = v_b;
		if (v_c < v_min_val) v_min_val = v_c;

		float v_max_val = v_a;
		if (v_b > v_max_val) v_max_val = v_b;
		if (v_c > v_max_val) v_max_val = v_c;

		float v_offset = -0.5f * (v_max_val + v_min_val);

		// calculate duty cycles (0.0 to 1.0)
		float duty_a = 0.5f + (v_a + v_offset);
		float duty_b = 0.5f + (v_b + v_offset);
		float duty_c = 0.5f + (v_c + v_offset);

		// clamp duties to 0.1 - 0.9
		if (duty_a > 0.9f) duty_a = 0.9f;
		if (duty_a < 0.1f) duty_a = 0.1f;
		if (duty_b > 0.9f) duty_b = 0.9f;
		if (duty_b < 0.1f) duty_b = 0.1f;
		if (duty_c > 0.9f) duty_c = 0.9f;
		if (duty_c < 0.1f) duty_c = 0.1f;

		// write duty cycles to timers
		TIM1->CCR1 = (uint32_t)(duty_a * 4199.0f);
		TIM1->CCR2 = (uint32_t)(duty_b * 4199.0f);
		TIM1->CCR3 = (uint32_t)(duty_c * 4199.0f);

		// trigger next SPI DMA transfer
		HAL_GPIO_WritePin(GPIOA, GPIO_PIN_15, GPIO_PIN_RESET);
		HAL_SPI_TransmitReceive_DMA(&hspi3, (uint8_t*)&as5048a_tx_buffer, (uint8_t*)&as5048a_rx_buffer, 1);
	}
}

#define FRAME_SYNC0 0xAA
#define FRAME_SYNC1 0x55
#define FRAME_LEN 17 // 2 sync + 2 seq + 12 (3 floats) + 1 checksum

void StartCurStreamTask(void *argument) {
  uint8_t frame[FRAME_LEN];

  for (;;) {
    while (cur_stream_tail != cur_stream_head) {
      CurSample_t s = cur_stream_buf[cur_stream_tail]; // local copy

      frame[0] = FRAME_SYNC0;
      frame[1] = FRAME_SYNC1;
      memcpy(&frame[2], &s.seq, 2);
      memcpy(&frame[4], &s.i_a, 4);
      memcpy(&frame[8], &s.i_b, 4);
      memcpy(&frame[12], &s.i_c, 4);

      uint8_t cksum = 0;
      for (int i = 2; i < 16; i++) {
        cksum ^= frame[i];
      }
      frame[16] = cksum;

      uint8_t result = CDC_Transmit_FS(frame, FRAME_LEN);
      if (result == USBD_OK) {
        cur_stream_tail = (uint16_t)((cur_stream_tail + 1) % CUR_STREAM_BUF_LEN);
      } else {
        osDelay(1); // USB busy so retry same sample, don't drop or corrupt it
      }
    }
    osDelay(1);
  }
}
/* USER CODE END 4 */

/* USER CODE BEGIN Header_StartStateTask */
void StartStateTask(void *argument)
{
  MX_USB_DEVICE_Init();

  HAL_GPIO_WritePin(GPIOC, GPIO_PIN_1, GPIO_PIN_SET);
  osDelay(50);

  DRV8301_WriteReg(0x02, 0x0400);
  osDelay(10);
  DRV8301_WriteReg(0x03, 0x0004);
  osDelay(10);

  HAL_ADCEx_InjectedStart_IT(&hadc1);
  HAL_ADCEx_InjectedStart(&hadc2);
  HAL_TIM_Base_Start(&htim1);
  osDelay(10);

  // calculate ADC Offsets
  uint32_t sum_a = 0;
  uint32_t sum_c = 0;
  for (int i = 0; i < 1000; i++) {
	  sum_a += raw_adc_a;
	  sum_c += raw_adc_c;
	  osDelay(1);
  }
  offset_a = (float)sum_a / 1000.0f;
  offset_c = (float)sum_c / 1000.0f;

  // Pre-load PWM Timers to 50% duty cycle
  TIM1->CCR1 = 2099;
  TIM1->CCR2 = 2099;
  TIM1->CCR3 = 2099;

  HAL_TIM_PWM_Start(&htim1, TIM_CHANNEL_1);
  HAL_TIMEx_PWMN_Start(&htim1, TIM_CHANNEL_1);
  HAL_TIM_PWM_Start(&htim1, TIM_CHANNEL_2);
  HAL_TIMEx_PWMN_Start(&htim1, TIM_CHANNEL_2);
  HAL_TIM_PWM_Start(&htim1, TIM_CHANNEL_3);
  HAL_TIMEx_PWMN_Start(&htim1, TIM_CHANNEL_3);
  __HAL_TIM_MOE_ENABLE(&htim1);

  for(;;)
  {
	if (HAL_GPIO_ReadPin(GPIOC, GPIO_PIN_0) == GPIO_PIN_RESET) {
		motor_state = STATE_OFF;
	}
	osDelay(100);
  }
}
/* USER CODE END Header_StartStateTask */

/* USER CODE BEGIN Header_StartTelemetryTask */
void StartTelemetryTask(void *argument)
{
  //char usb_buffer[128];
  //int counter = 0;
  for(;;) {
    //if (motor_state == STATE_RUNNING) { 
      // format CSV message for telemetry
      //int len = snprintf(usb_buffer, sizeof(usb_buffer),
        //                "%d | Vel_Target: %.2f, Vel_Actual: %.2f, Iq_Target: %.2f, Iq_Actual: %.2f, theta: %.2f, theta_elec: %.2f\r\n",
        //                counter, target_vel_rads, current_vel_rads, target_iq, i_q, prev_theta_mech, global_theta_elec);

      //CDC_Transmit_FS((uint8_t*)usb_buffer, len);
      //counter++;
    //}
	  // 50Hz telemetry
	  osDelay(30);
  }
}
/* USER CODE END Header_StartTelemetryTask */

void HAL_TIM_PeriodElapsedCallback(TIM_HandleTypeDef *htim)
{
  if (htim->Instance == TIM6)
  {
    HAL_IncTick();
  }
}

void Error_Handler(void)
{
  __disable_irq();
  while (1)
  {
  }
}

#ifdef USE_FULL_ASSERT
void assert_failed(uint8_t *file, uint32_t line)
{
}
#endif /* USE_FULL_ASSERT */

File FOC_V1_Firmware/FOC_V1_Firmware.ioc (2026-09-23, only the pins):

Mcu.UserName=STM32F405RGTx
PA0-WKUP.Signal=ADCx_IN0
PA1.Signal=ADCx_IN1
PA10.Signal=S_TIM1_CH3
PA11.Signal=USB_OTG_FS_DM
PA12.Signal=USB_OTG_FS_DP
PA15.Signal=GPIO_Output
PA2.Signal=ADCx_IN2
PA3.Signal=ADCx_IN3
PA8.Signal=S_TIM1_CH1
PA9.Signal=S_TIM1_CH2
PB13.Signal=TIM1_CH1N
PB14.Signal=TIM1_CH2N
PB15.Signal=TIM1_CH3N
PB3.Signal=SPI1_SCK
PB4.Signal=SPI1_MISO
PB5.Signal=SPI1_MOSI
PB8.Signal=CAN1_RX
PB9.Signal=CAN1_TX
PC0.Signal=GPXTI0
PC1.Signal=GPIO_Output
PC10.Signal=SPI3_SCK
PC11.Signal=SPI3_MISO
PC12.Signal=SPI3_MOSI
PC2.Signal=GPIO_Output
PD2.Signal=GPIO_Output
PH0-OSC_IN.Signal=RCC_OSC_IN
PH1-OSC_OUT.Signal=RCC_OSC_OUT

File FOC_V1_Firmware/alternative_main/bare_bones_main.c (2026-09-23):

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
/* Includes ------------------------------------------------------------------*/
#include "main.h"
#include "cmsis_os.h"
#include "usb_device.h"

/* USER CODE BEGIN Includes */
#include "usbd_cdc_if.h"
#include <stdio.h>
#include <math.h>
/* USER CODE END Includes */

ADC_HandleTypeDef hadc1;
ADC_HandleTypeDef hadc2;
ADC_HandleTypeDef hadc3;

CAN_HandleTypeDef hcan1;

SPI_HandleTypeDef hspi1;
SPI_HandleTypeDef hspi3;
DMA_HandleTypeDef hdma_spi3_rx;
DMA_HandleTypeDef hdma_spi3_tx;

TIM_HandleTypeDef htim1;

/* Definitions for StateTask */
osThreadId_t StateTaskHandle;
const osThreadAttr_t StateTask_attributes = {
  .name = "StateTask",
  .stack_size = 128 * 4,
  .priority = (osPriority_t) osPriorityNormal,
};
/* Definitions for TelemetryTask */
osThreadId_t TelemetryTaskHandle;
const osThreadAttr_t TelemetryTask_attributes = {
  .name = "TelemetryTask",
  .stack_size = 512 * 4,
  .priority = (osPriority_t) osPriorityNormal,
};
/* USER CODE BEGIN PV */
// AS5048A Read Angle Command (Address 0x3FFF + Read Bit + Even Parity Bit = 0xFFFF)
uint16_t as5048a_tx_buffer = 0xFFFF;
uint16_t as5048a_rx_buffer = 0x0000;
volatile int start_motor = 0;
/* USER CODE END PV */

void SystemClock_Config(void);
static void MX_GPIO_Init(void);
static void MX_DMA_Init(void);
static void MX_ADC1_Init(void);
static void MX_ADC2_Init(void);
static void MX_ADC3_Init(void);
static void MX_TIM1_Init(void);
static void MX_SPI1_Init(void);
static void MX_SPI3_Init(void);
static void MX_CAN1_Init(void);
void StartStateTask(void *argument);
void StartTelemetryTask(void *argument);

/**
  * @brief  The application entry point.
  * @retval int
  */
int main(void)
{

  /* MCU Configuration--------------------------------------------------------*/

  /* Reset of all peripherals, Initializes the Flash interface and the Systick. */
  HAL_Init();

  /* Configure the system clock */
  SystemClock_Config();

  /* Initialize all configured peripherals */
  MX_GPIO_Init();
  MX_DMA_Init();
  MX_ADC1_Init();
  MX_ADC2_Init();
  MX_ADC3_Init();
  MX_TIM1_Init();
  MX_SPI1_Init();
  MX_SPI3_Init();
  MX_CAN1_Init();
  /* Init scheduler */
  osKernelInitialize();

  /* USER CODE BEGIN RTOS_MUTEX */
  /* add mutexes, ... */
  /* USER CODE END RTOS_MUTEX */

  /* USER CODE BEGIN RTOS_SEMAPHORES */
  /* add semaphores, ... */
  /* USER CODE END RTOS_SEMAPHORES */

  /* USER CODE BEGIN RTOS_TIMERS */
  /* start timers, add new ones, ... */
  /* USER CODE END RTOS_TIMERS */

  /* USER CODE BEGIN RTOS_QUEUES */
  /* add queues, ... */
  /* USER CODE END RTOS_QUEUES */

  /* Create the thread(s) */
  /* creation of StateTask */
  StateTaskHandle = osThreadNew(StartStateTask, NULL, &StateTask_attributes);

  /* creation of TelemetryTask */
  TelemetryTaskHandle = osThreadNew(StartTelemetryTask, NULL, &TelemetryTask_attributes);

  /* USER CODE BEGIN RTOS_THREADS */
  /* add threads, ... */
  /* USER CODE END RTOS_THREADS */

  /* USER CODE BEGIN RTOS_EVENTS */
  /* add events, ... */
  /* USER CODE END RTOS_EVENTS */

  /* Start scheduler */
  osKernelStart();

  /* We should never get here as control is now taken by the scheduler */

  /* Infinite loop */
  /* USER CODE BEGIN WHILE */
  while (1)
  {
    /* USER CODE END WHILE */

    /* USER CODE BEGIN 3 */
  }
  /* USER CODE END 3 */
}

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
/* USER CODE BEGIN 4 */
// helper function for reading DRV8301 register
uint16_t DRV8301_ReadReg(uint8_t addr) {
	uint16_t tx_data;
	uint16_t rx_data;

	// FRAME 1: Send the Read Command
	// bit 15 = 1 (for read), bit 14-11 = address to read, bit 10-0 = 0
	tx_data = (1 << 15) | ((addr & 0x0F) << 11);

	HAL_GPIO_WritePin(GPIOD, GPIO_PIN_2, GPIO_PIN_RESET); // pull CS LOW
	// Note: even though we pass (uint8_t*), the HAL knows command is 16-bit because of CubeMX config
	HAL_SPI_TransmitReceive(&hspi1, (uint8_t*)&tx_data, (uint8_t*)&rx_data, 1, 100);
	HAL_GPIO_WritePin(GPIOD, GPIO_PIN_2, GPIO_PIN_SET); // pull CS HIGH

	// Small delay between frames
	for(volatile int i=0; i<50; i++);

	// FRAME 2: send a dummy word to clock out the data
	tx_data = 0x0000; // dummy word
	HAL_GPIO_WritePin(GPIOD, GPIO_PIN_2, GPIO_PIN_RESET); // pull CS LOW
	HAL_SPI_TransmitReceive(&hspi1, (uint8_t*)&tx_data, (uint8_t*)&rx_data, 1, 100);
	HAL_GPIO_WritePin(GPIOD, GPIO_PIN_2, GPIO_PIN_SET); // pull CS HIGH

	// DRV8301 returns the data in the lower 11 bits (bits 10-0)
	return (rx_data & 0x07FF);
}

// Helper function for writing DRV8301 register
void DRV8301_WriteReg(uint8_t addr, uint16_t data) {
	uint16_t tx_data;
	uint16_t rx_data;

	tx_data = (0 << 15) | ((addr & 0xF) << 11) | (data & 0x07FF);

	HAL_GPIO_WritePin(GPIOD, GPIO_PIN_2, GPIO_PIN_RESET);
	HAL_SPI_TransmitReceive(&hspi1, (uint8_t*)&tx_data, (uint8_t*)&rx_data, 1, 100);
	HAL_GPIO_WritePin(GPIOD, GPIO_PIN_2, GPIO_PIN_SET);

	for(volatile int i = 0; i < 50; i++);
}


// SPI DMA Completion Callback (Fires automatically when DMA finishes)
void HAL_SPI_TxRxCpltCallback(SPI_HandleTypeDef *hspi)
{
    // Check if it was SPI3 (The Encoder) that finished
    if (hspi->Instance == SPI3)
    {
        // The transfer is done, pull CS HIGH to end the frame
        HAL_GPIO_WritePin(GPIOA, GPIO_PIN_15, GPIO_PIN_SET);
    }
}
/* USER CODE END 4 */
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

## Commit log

2026-07-26 first iteration of FOC PCB
    [DCA0056A.stp, FOC_V1_PCB.kicad_pcb, FOC_V1_PCB.kicad_sch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]
2026-07-30 V1.1: improved clearances, connectors, and seperated FOC board with encoder board
    [Encoder_Module_PCB.kicad_pcb, Encoder_Module_PCB.kicad_sch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]
2026-07-31 rearranged some file and directories
    [Encoder_Module_PCB-B_Cu.gbl, Encoder_Module_PCB-B_Mask.gbs, Encoder_Module_PCB-B_Paste.gbp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]
2026-08-29 new V1.2 PCB and tweaked mechanical rig
    [0000. Main Assembly.SLDASM, 3D print plate file.3mf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]
2026-09-11 new V1.3 design (fixed USB-C)
    [FOC_V1_PCB-B_Cu.gbl, FOC_V1_PCB-B_Mask.gbs, FOC_V1_PCB-B_Paste.gbp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]
2026-09-23 added bare-metal STM32 C firmware for open-loop commutation, current sensing and encoder angle telemetry, and python script for telemetry graphing
2026-09-28 Achieved true FOC velocity and current control in firmware
2026-10-01 tuned velocity and current PI controllers, added zero electrical angle calibration, breakaway torque injection/stall-kick/startup boost, making startup more consistent
    [accident_FOC.c, bare_bones_main.c, calibrate.c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]
2026-10-03 fixed calibration bug decreased kickstart duration for more reliability of startup at higher speeds
    [FOC_CurTelem.c, barebones_openloop_plotter.py, current_plotter.py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]
2026-10-03 better current sensing telemetry to diagnose if there is a current sensing asymmetry and finishing up the project
2026-10-03 added BOM to repo
2026-11-04 gitignore Kicad history and backups
2026-11-08 changed BOM to markdown for easier viewing
2026-11-08 added BOM_and_Schematics directory and added schematic pdfs

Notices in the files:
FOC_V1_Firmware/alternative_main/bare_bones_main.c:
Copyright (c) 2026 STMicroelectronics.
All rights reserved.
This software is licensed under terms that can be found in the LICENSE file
